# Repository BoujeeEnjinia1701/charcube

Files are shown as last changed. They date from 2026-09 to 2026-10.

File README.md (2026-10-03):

# CharCube

     

**Area:** CleanTech · **TRL:** 3 of 9 (proof of concept on paper; TRL 4 on hold) · **Value-engineering target:** $320 USD (hypothetical control target; estimated cost of the constructable design $546, $226 over, of which the lifting aid is $160; safety kit listed separately) · **Difficulty:** 2 of 5

Batch retort kiln that turns biomass into biochar, with a secondary burner that cleans up the syngas and a jacket that recovers heat for hot water.

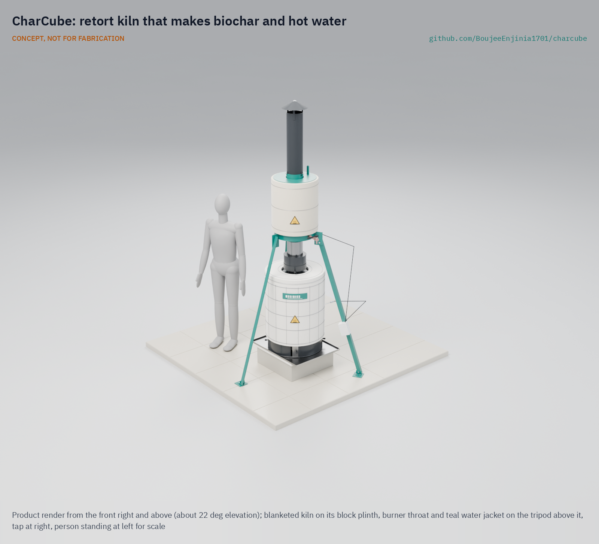
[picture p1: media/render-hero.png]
CharCube: retort kiln that makes biochar and hot water, product render


[Exploded render](media/render-exploded.png) · [Detail render](media/render-detail.png) · [Interactive 3D model](media/viewer.html) · [Concept blueprint (PDF)](media/concept-blueprint.pdf) · [General arrangement CCB-DWG-001 (PDF)](cad/drawings/CCB-DWG-001.pdf) · [Calculations CCB-CAL-001](docs/04-calcs/01-sizing.md) · [Prototype build plan](docs/05-build-plan.md) · [Design decisions](docs/06-design-decisions.md) · [Review note](docs/REVIEW.md)

## Concept rationale

A retort keeps air away from the residue, so it chars instead of burning, and the gas it gives off is burned in the kiln rather than vented. Nesting one steel drum inside another is the simplest way to build that: the gas fire in the gap heats the retort, a burner throat cleans up what is left, and the same flue heats water in an open jacket. Drums, plain pipe, bolts and one welded tank are available almost anywhere crops are grown, so the design can be copied by a village fabricator or a college workshop.

Publishing it as open hardware matters because low-cost kilns rarely come with numbers. CharCube publishes its model, calculations and a temperature logger, so users and researchers can check whether a batch reached the temperatures that make stable char, and improve the design where it falls short.

## Burning platform

In India alone, farms generate about 500 Mt of crop residue a year and burn about 100 Mt of it in the field; that smoke was linked to an estimated 44,000 to 98,000 premature deaths a year between 2003 and 2019 ([Lan et al. 2022, *Nature Communications*](https://www.nature.com/articles/s41467-022-34093-z)). Worldwide, the WHO estimates that outdoor air pollution caused 4.2 million premature deaths in 2019, when 99 % of the world's population lived where its air quality guideline levels were not met ([WHO fact sheet](https://www.who.int/news-room/fact-sheets/detail/ambient-(outdoor)-air-quality-and-health)).

Making char badly is not the answer either. Field measurements found about 54 g of methane per kilogram of charcoal from traditional kilns and about 24 g/kg from improved retorts ([Sparrevik et al. 2015, *Biomass and Bioenergy*](https://www.sciencedirect.com/science/article/abs/pii/S0961953414005170)), and methane at that rate cancels a large part of the carbon the char stores. The gas has to be burned, and the heat is worth using.

## Where it could be used

### By industry

| Industry | Use |
| --- | --- |
| Smallholder farming | Turn stalks, cobs and bundled straw into biochar for the farm's own soil instead of burning them in the field |
| Farmer cooperatives and agricultural NGOs | Shared kilns with logged batches, as a residue service between harvests |
| Agricultural research and extension | A cheap, repeatable kiln with temperature records for feedstock and char quality trials |
| Orchards, vineyards and nurseries | Char prunings on site and use the hot water for cleaning |
| Carbon removal pilots | Small, documented batches as a starting point for biochar measurement and reporting |
| Education and makerspaces | A teaching example of pyrolysis, heat transfer and emissions control |

### By country or region

| Country or region | Why it matters there |
| --- | --- |
| India (Punjab, Haryana, Uttar Pradesh) | About 100 Mt of residue burned a year; these three states account for 67 to 90 % of the linked deaths ([Lan et al. 2022](https://www.nature.com/articles/s41467-022-34093-z)) |
| Southeast Asia | The region produces about 100 to 140 Mt of rice straw a year; with two or three crops a year there is little time for straw to decompose, and open-field burning has risen despite bans ([Van Hung et al. 2020](https://link.springer.com/chapter/10.1007/978-3-030-32373-8_1)) |
| East Africa | Pilot units of a low-cost retort kiln have already been established in East Africa ([Adam 2009, *Renewable Energy*](https://doi.org/10.1016/j.renene.2008.12.009)), so local fabricators and users have seen the principle work |
| Brazil (São Paulo) | [State Law 11,241 of 2002](https://www.al.sp.gov.br/repositorio/legislacao/lei/2002/lei-11241-19.09.2002.html) phases out pre-harvest sugarcane straw burning, by 2021 on land that can be harvested by machine and by 2031 on the rest ([Instituto de Economia Agrícola, 2014](https://iea.agricultura.sp.gov.br/ftpiea/AIA/AIA-31-2014.pdf)), so growers need other uses for residue |
| United States (California) | Rice straw burning in the Sacramento Valley has been capped since 2001 at 25 % of each grower's planted acres ([Health and Safety Code 41865](https://www.countyofglenn.net/sites/default/files/Air_Pollution_Control_District/CARSRA%20%20HSC%2041865.pdf), as published by the Glenn County Air Pollution Control District) |
| Europe | The [European Biochar Certificate](https://www.european-biochar.org/en) sets standards for char quality and production records that a logged kiln can help research groups work toward |

## What sparked the idea

The idea traces back to the Improved Charcoal Production System, or Adam retort, a low-cost retort kiln piloted in India and East Africa and described by J. C. Adam in *Renewable Energy* in 2009 ([Adam 2009](https://doi.org/10.1016/j.renene.2008.12.009)). It burns the harmful volatiles in a hot chamber instead of releasing them and uses the heat of that flare to speed carbonization, reaching 30 to 42 % efficiency against 10 to 22 % for earth mounds and cutting emissions by up to 75 %. It was built for wood charcoal. CharCube asks whether the same principle can be shrunk to two steel drums for crop residue, with the leftover heat sent into water.

## Problem

Crop residue gets burned in the open, releasing carbon and smoke. India alone burns about 100 Mt of residue a year in the field, linked to tens of thousands of premature deaths from smoke. Design with, not for: requirements must come from co-design sessions and field trials with the intended users through a local partner.

## Concept

Batch retort kiln that turns biomass into biochar, with a secondary burner that cleans up the syngas and a jacket that recovers heat for hot water.

A 114 L steel drum packed with 12.0 kg of bundled residue sits inside a 200 L drum. Gas from the heated residue burns in the gap between the drums and again in a burner throat fed by an air shroud, then passes a spiral baffle inside an open-vented, blanketed jacket that holds about 61 L of water. The TRL 3 calculations (CCB-CAL-001 v0.6, central estimates) give about 3.0 kg of biochar per batch in a burn of about 4.5 h with about 3.7 kg of wood, and about 11.5 MJ of hot water. A bolted swinging arm on a post with a hand winch lifts the drained 47 kg heat-recovery unit off the kiln for loading. Value-engineering target: USD 320. Estimated cost of the constructable design: USD 546 (USD 226 over the target), with every part priced; burn time, hot water and start-up wood are at risk. Nothing is measured yet.

Full design precis: [docs/02-concept.md](docs/02-concept.md)

## Key components

- Nested steel drum pair: 200 L outer drum and 114 L inner retort
- Burner throat with secondary air shroud (30 air holes)
- Flue pipe with conical rain cap
- Open-vented water jacket around the flue (replaces the copper coil in the first sketch; decided by Amish, 2026-09-25), with a spiral baffle insert and a mineral wool blanket (decided by Amish, 2026-09-25)
- Ceramic fibre blankets on the outer drum, lid and top band
- Thermocouple logger: retort core, throat exit and a plinth block
- Lifting aid: a swinging arm on a post with a hand winch, for the heat-recovery unit

The priced bill of materials is in [bom/bom.csv](bom/bom.csv). The parametric model is [cad/src/model.py](cad/src/model.py), with STEP and STL exports in `cad/step/` and `cad/stl/`.

## Building the prototype

The [prototype build plan](docs/05-build-plan.md) (CCB-BLD-001) shows how to make and fit every one of the 26 components, in build order, with a making sketch for each made part, close-ups of the joints and a picture for every assembly step. Most of the work is cutting, drilling, rolling and riveting two used drums, plain pipe and sheet; the water jacket is the one welded part. Writing the plan made the design buildable: the jacket now stands on angle legs bolted to fins on its shell, the throat stands in a riveted collar, and the flue rests on the jacket on three clips (CCB-DDR-003, open for review). It is a plan, not yet built; building and testing to it is TRL 4 work, which is on hold.

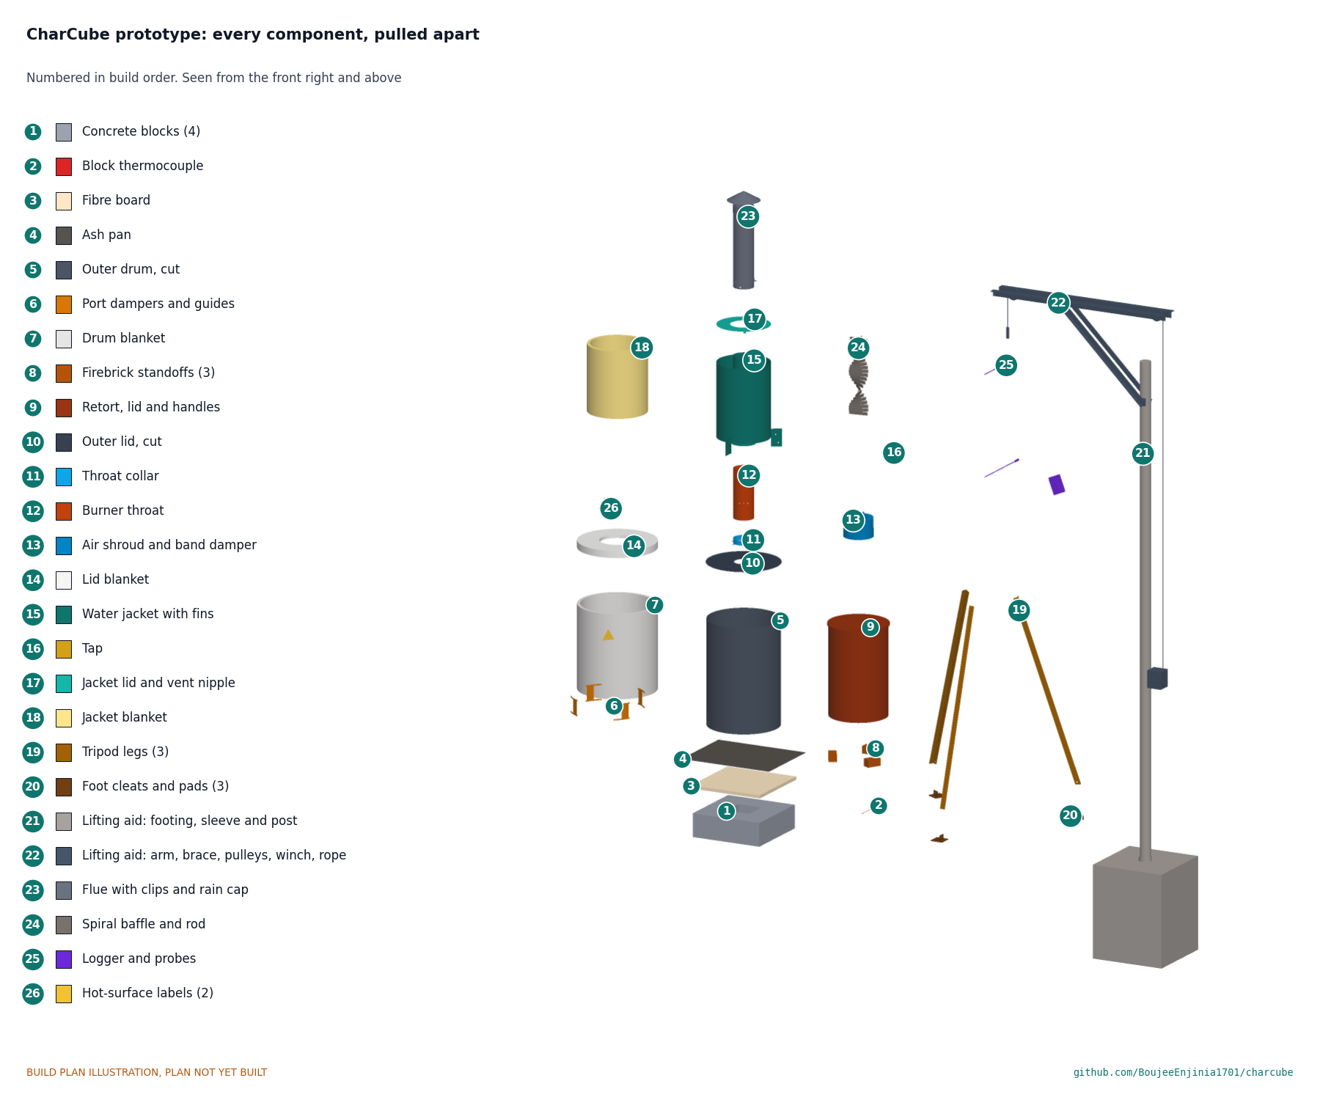
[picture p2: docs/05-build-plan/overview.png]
CharCube prototype: every component, pulled apart and numbered in build order


## Safety

> Involves open flame, hot surfaces (about 125 to 260 °C outside, 400 to 650 °C gas inside), flammable and toxic pyrolysis gas (including carbon monoxide) and water near boiling. Operate outdoors only, at least 5 m from structures and dry vegetation, with the required safety kit (fire suppression, gloves, eye protection) on hand. Never open the kiln while hot, never seal the water jacket, and never use drums that held fuel or chemicals. See the safety section of the [design precis](docs/02-concept.md).

## Repository layout

| Folder | Contents |
| --- | --- |
| `docs/` | Problem, concept, requirements, calculations and design decisions |
| `cad/src/` | build123d Python source, the source of truth for all geometry |
| `cad/step/`, `cad/stl/` | Exported models for FreeCAD, other CAD tools and printing |
| `cad/drawings/` | 2D sketches and dimensioned drawings |
| `bom/` | Bill of materials |
| `electronics/` | KiCad schematics and PCB layouts |
| `firmware/` | Microcontroller code |
| `media/` | Renders, perspectives and photos |
| `build-log/` | Dated prototyping notes |

## Documentation

Controlled documents follow the portfolio [documentation standard](.kit/STANDARDS.md). Each carries a document ID (CCB-PRC-001 for the precis), a version and a revision history. Branded PDFs are built with `python .kit/render.py` and attached to GitHub Releases when a document is tagged, for example `CCB-PRC-001/v1.0`.

## Credits

Designed by Amish Chadha. See [CONTRIBUTORS.md](CONTRIBUTORS.md) for roles. To cite this design, use [CITATION.cff](CITATION.cff) (GitHub shows it as "Cite this repository").

AI assistance (Claude) was used to accelerate concept renders, prototype documentation and first-pass sizing calculations. Design direction and all decisions are Amish Chadha's, recorded in this repository's decision records (`docs/decisions/`).

## Licenses

- **Hardware** (CAD, drawings, BOM, electronics): [CERN-OHL-S v2](LICENSE)
- **Software** (firmware, scripts, notebooks): [MIT](LICENSE-SOFTWARE)

A project of the [Design Molecule](https://designmolecule.com) lab.

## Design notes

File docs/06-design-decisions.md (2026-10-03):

---
doc_id: CCB-DEC-001
title: CharCube design decisions register
project: CharCube
doc_type: Design decisions register
version: "0.5"
status: Draft
date: '2026-10-03'
author: Amish Chadha
license: CERN-OHL-S-2.0
revisions:
  - version: "0.1"
    date: '2026-09-30'
    author: Amish Chadha
    change: Register opened with the open decisions from the review note, the decision records and the build plan work
  - version: "0.2"
    date: '2026-10-01'
    author: Amish Chadha
    change: Budget treated as a value-engineering target
  - version: "0.3"
    date: '2026-10-02'
    author: Amish Chadha
    change: 'Amish approved the recommendations for all seven open decisions (2026-10-02); CCB-DDR-003 accepted; moved to decisions made; value-engineering note on the decided additions'
  - version: "0.4"
    date: '2026-10-02'
    author: Amish Chadha
    change: 'Approved follow-ups carried out: every part priced; value-engineering result restated'
  - version: "0.5"
    date: '2026-10-03'
    author: Amish Chadha
    change: "Amish accepted the cost overrun against the value-engineering target on 2026-10-03; row added to decisions made; value engineering section updated"
---

# CharCube design decisions register

Every design decision still to be made, and every decision made, in one place. Each decision is argued in full in its decision record under `docs/decisions/`; this register is the index Amish works from. The build plan (`docs/05-build-plan.md`, CCB-BLD-001) describes the design as it stands and does not list open decisions.

## Open decisions

None. All open decisions were decided on 2026-10-02.

## To confirm when parts are bought

| # | What to confirm | Why it matters | Source |
| --- | --- | --- | --- |
| 1 | The two drums' actual diameters and heights, and the gap between them (at least 40 mm) | Drum sizes vary by maker; the gas gap, brick positions and probe slot height depend on them | CCB-DDR-003 |
| 2 | The 160 mm pipe's actual outside diameter and the 168 mm sleeve's bore | The collar is rolled to the pipe; the slip joints need about 2 mm clearance | CCB-DDR-003, P2 and P8 |
| 3 | The effect of the 150 mm lid hole on draft (8 % less area than the throat bore), confirmed at the first burn (decided 2026-10-02) | The draft calculation does not model the lid entry; margin 2.4 at peak | CCB-DDR-003, P2; CCB-CAL-001 section 6 |
| 4 | Probe lengths (500 mm and 300 mm) and sheath rating | The core probe must reach the retort axis from outside the blanket | CCB-DDR-003, P12 |
| 5 | Blanket roll widths (681 mm drum strip, 540 mm jacket strip) | Sets how many joins each wrap has | Build plan sections 3.4, 3.14 |
| 6 | Prices of every BOM line once quoted, including the parts added for construction | The estimated cost against the value-engineering target rests on indicative prices | CCB-CAL-001 section 11 |
| 7 | The factor of 3 on gas-side heat transfer and the four velocity heads of pressure loss assumed for the spiral baffle | Heat to water (R6) and draft depend on them; they are assumptions until measured at TRL 4 | CCB-CAL-001 sections 1, 7 |

## Value engineering

Value-engineering target: USD 320. Estimated cost of the constructable design: USD 546 (USD 226 over the target).

Amish accepted this overrun on 2026-10-03: the estimated cost of USD 546 against the USD 320 target (USD 226 over), with the lifting aid (USD 160) counted in the kit cost as it stands. Amish: "Cost over target - i accept all the cost variations and overruns". It stays reported against the target as an accepted overrun, and the savings below remain worth trying.

Every BOM line is priced, with its basis in the line's notes (2026-10-02). The parts added for construction add USD 17 to the earlier USD 319; the additions decided on 2026-10-02 add USD 186: the fibre board USD 28, the block thermocouple USD 10, the hot-surface labels USD 8 and the lifting aid USD 160 (CCB-CAL-001 section 11).

- **Main cost drivers:** the lifting aid (USD 160), the welded water jacket with its spiral baffle insert, the logger, the plinth with its fibre board, the ceramic fibre blankets and the two drums (see `bom/bom.csv`).
- **Savings worth trying:** sharing one lifting aid among several kilns on a site, or hanging the winch from an existing strong beam or tree where there is one (most of USD 160); leaving the fibre board off later builds if a measured burn without it keeps the blocks under about 150 °C (USD 28, as decided); a cheaper logger box; a clay and ash render in place of the side blanket (about USD 25, from the TRL 2 review); and re-pricing the small parts at purchase.

## Decisions made

| Date | Decision | Decided by | Record |
| --- | --- | --- | --- |
| 2026-09-25 | TRL 2 review items 1 to 8 and 10: open-vented annular water jacket; $300 kiln budget with the safety kit separate; nested-drum retort; bundled straw and stalks first; burner throat with preheated air; logger as standard; ceramic fibre blanket; tripod-carried jacket; keep the name | Amish: "proceed with all of your recommendations across all batches. Make sure we don't proceed to TRL 4 on any of them." | CCB-DDR-001 |
| 2026-09-25 | Items 11 to 16: air shroud in place of the 25 mm ring; spiral baffle insert and jacket blanket; lid and top band blanket; R5 relaxed to 5 h; R9 restated to 700 °C; safety kit stated in R10 and the BOM notes | Amish: "i accept all your recommendations, go with them across all repos." | CCB-DDR-002 |
| 2026-09-26 | Item 17: budget top-up from $300 to $320 for kiln parts | Amish: "I am ok with the budget top ups." | CCB-DDR-002, Table 1a |
| 2026-09-25 | TRL 4 on hold | Amish | `project.yaml`; CCB-DDR-001 |
| 2026-09-30 | Make the design physically buildable while drawing the build plan; outstanding decisions kept in this register, not in the build plan | Amish: "If you are realising that the design cannot be built as per concept - fix the design assumptions to match and be physically feasible as you draw the illustrations." | CCB-DDR-003 (accepted on 2026-10-02, below) |
| 2026-10-02 | Design for construction accepted: the twelve changes of Table 1 and their knock-on changes, as made; the first burn confirms that the 150 mm lid hole (8 % less area than the throat bore) does not limit draft | Amish: "i approve your recommendations for all 555 open decisions." | CCB-DDR-003, Table 1 |
| 2026-10-02 | Plinth: a 25 mm ceramic fibre board between the pan and the blocks from the first burn, with a thermocouple on a block; the board is dropped on later builds only if a measured burn without it keeps the blocks under about 150 °C | Amish: "i approve your recommendations for all 555 open decisions." | CCB-DDR-003, A2 |
| 2026-10-02 | Jacket sleeve: the welder flares the bottom 20 mm of the sleeve to about 190 mm so it guides itself onto the throat | Amish: "i approve your recommendations for all 555 open decisions." | CCB-DDR-003, A3 |
| 2026-10-02 | Heat-recovery unit: a lifting aid, a swinging arm on a post or a hand winch, is designed for the first build; users are asked through the partner how it should work, not whether it is needed | Amish: "i approve your recommendations for all 555 open decisions." | CCB-PRC-001, open questions |
| 2026-10-02 | First region, residue and partner: kept open under the portfolio rule, chosen by this rule: a region where rice or wheat straw is still burned in the open, with a partner that already runs residue or biochar trials. First candidate to approach: an agricultural university's extension service, for example Punjab Agricultural University in India | Amish: "i approve your recommendations for all 555 open decisions." | CCB-DDR-001 item 9; CCB-DDR-002 Table 2 |
| 2026-10-02 | Rain cap: the conical cap is adopted in the model and drawings, on the three flat-bar legs and 60 mm gap set by the design for construction | Amish: "i approve your recommendations for all 555 open decisions." | `docs/REVIEW.md`, 2026-09-26, appearance item 1 |
| 2026-10-02 | Hot-surface labels: durable ISO 7010 W017 hot-surface warning labels for the drum blanket and the jacket are added to BOM line 14 | Amish: "i approve your recommendations for all 555 open decisions." | `docs/REVIEW.md`, 2026-09-26, appearance item 5 |
| 2026-10-03 | Cost overrun accepted: the estimated cost of USD 546 against the USD 320 target (USD 226 over), with the lifting aid (USD 160) counted in the kit cost as it stands | Amish: "Cost over target - i accept all the cost variations and overruns" | [REVIEW.md](REVIEW.md), session 2026-10-03 |

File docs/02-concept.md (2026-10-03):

---
doc_id: CCB-PRC-001
title: CharCube design precis
project: CharCube
doc_type: Design precis
version: "0.9"
status: Draft
date: '2026-10-02'
author: Amish Chadha
license: CERN-OHL-S-2.0
revisions:
- version: "0.1"
  date: '2026-09-24'
  author: Amish Chadha
  change: Initial scaffold
- version: "0.2"
  date: '2026-09-25'
  author: Amish Chadha
  change: Populate to TRL 2 (architecture, first-order numbers, design choices, safety, media)
- version: "0.3"
  date: '2026-09-25'
  author: Amish Chadha
  change: TRL 3 update; decisions of 2026-09-25 recorded (CCB-DDR-001), numbers replaced by CCB-CAL-001 results, air shroud replaces the 25 mm ring, parametric model and CCB-DWG-001
- version: "0.4"
  date: '2026-09-25'
  author: Amish Chadha
  change: Recommendations accepted by Amish (DDR-002); spiral baffle insert, jacket blanket and lid blanket added, 30 throat air holes, numbers from CCB-CAL-001 v0.2, CCB-DWG-001 Rev P2
- version: "0.5"
  date: '2026-09-26'
  author: Amish Chadha
  change: Budget top-up approved by Amish ($320, CCB-DDR-002 item 17); R10 met
- version: "0.6"
  date: '2026-09-30'
  author: Amish Chadha
  change: Design made constructable (CCB-DDR-003, Draft); components table, masses and probe routes updated; build plan CCB-BLD-001
- version: "0.7"
  date: '2026-10-01'
  author: Amish Chadha
  change: Budget treated as a value-engineering target
- version: "0.8"
  date: '2026-10-02'
  author: Amish Chadha
  change: 'Decisions of 2026-10-02 carried in: lifting aid, fibre board under the drum floor, hot-surface labels, conical rain cap, partner selection rule and first candidate'
- version: "0.9"
  date: '2026-10-02'
  author: Amish Chadha
  change: 'Approved follow-ups carried out: lifting aid designed and priced (item 18), fibre board and block thermocouple, sleeve flare, labels; every part priced ($546, R10 not met); outlet 2.72 m'
---

# CharCube design precis

CharCube is a batch retort kiln made from a 114 L (30 US gal) steel drum sealed inside a 200 L (55 US gal) drum. Crop residue packed into the inner drum (the retort) is heated without air; the gas it gives off escapes through holes in the retort base and burns in the gap between the drums, which keeps the process going. The flame and any unburned gas then pass through a burner throat fed with secondary air, and the hot flue gas rises past a spiral baffle through an open-vented, blanketed water jacket of about 61 L before leaving a flue 2.70 m above the ground. The TRL 3 calculations (CCB-CAL-001 v0.4) give, for the central case: 12.0 kg of air-dry residue per batch makes about 3.0 kg of biochar in a burn of about 4.5 h using about 3.7 kg of wood, and heats the water by about 45 K (11.5 MJ). Against the $320 value-engineering target (a hypothetical control target), the estimated cost of the kiln parts is $319, $1 under the target, so cost (R10) is within the target; burn time, hot water and start-up wood (R5, R6, R8) are at risk.

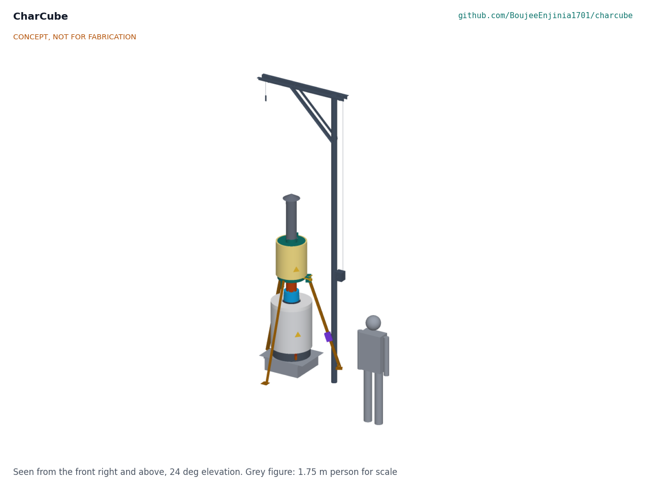
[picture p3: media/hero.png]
Hero render


*Figure 1. CharCube on its block plinth with the jacket tripod, beside a 1.75 m person for scale. TRL 3 parametric model (`cad/src/model.py`).*

## How it works

1. **Load.** The retort is packed to 600 mm with 12.0 kg of air-dry residue (bundled straw, stalks, cobs or prunings), its lid is clamped on, and it stands upright on three firebrick standoffs inside the outer drum. The outer lid, carrying the burner throat and its blanket, goes on top, and the tripod carrying the drained jacket and flue is set over it so the jacket sleeve slips over the top of the throat.
2. **Light.** Dry wood is lit in the 53 mm annulus around the retort and in the space beneath it; about 1.7 kg brings the kiln up to temperature, and more is fed to keep the annulus hot (about 3.7 kg in all, central estimate). Primary air enters through four ports near the base of the outer drum.
3. **Pyrolysis.** After about 30 to 45 min the retort contents pass about 300 °C and start to release gas and tar vapor. The gas leaves through holes in the retort base, meets the fire and burns. The retort gas then supplies much of the heat, but CCB-CAL-001 shows that wood must still be fed to hold the annulus near 650 °C for the whole burn. The target is a retort core of 450 to 600 °C for at least 30 min. Heat conducts slowly into the packed charge, so the core reaches 450 °C about 4.0 h after lighting (2.9 to 6.5 h).
4. **Clean-up burn.** Everything leaving the outer drum passes the burner throat, a 160 mm steel pipe 400 mm long. A 230 mm sleeve (the air shroud) around its base admits secondary air, preheated by the throat wall, through 30 holes of 12 mm, so gas that escaped the annulus fire burns there instead of leaving as smoke and methane.
5. **Heat recovery.** The hot gas (about 400 to 465 °C at the throat exit, after mixing with the secondary air) rises through a 168 mm sleeve that forms the centre of an annular water jacket. The gas flow is laminar or transitional, so a twisted steel strip (the spiral baffle insert) swirls it against the sleeve wall, and a mineral wool blanket on the jacket shell keeps the heat in the water. The jacket is open at the top, so it cannot build pressure. Hot water is drawn from a tap at its base.
6. **Finish and cool.** When the flame at the throat dies back (about 4.5 h after lighting; 3.4 to 7.0 h), the primary ports and secondary damper are closed and the kiln is left sealed overnight. The char cools without air, so it does not burn away.
7. **Unload and log.** Next morning the tripod unit and lid are lifted off, the core probe is pulled out, the retort (about 15.5 kg with its char) is lifted out by its two U-bolt handles, and the char is tipped out, quenched or wetted, weighed and crushed. A two-channel thermocouple logger records the retort core and the throat exit every 10 s, giving a record of peak temperature and time at temperature for each batch.

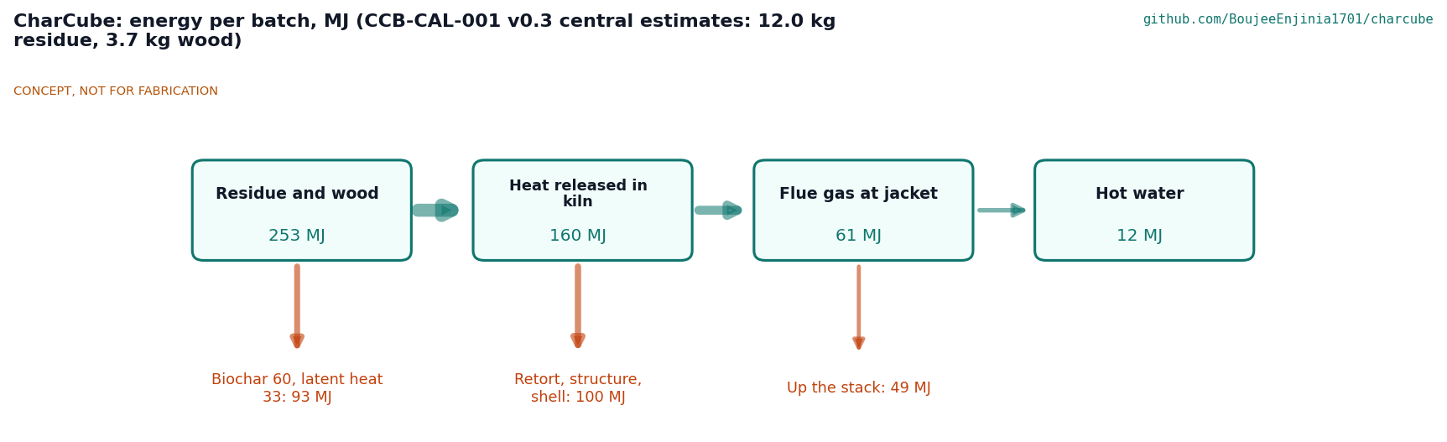
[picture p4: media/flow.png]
Energy flow


*Figure 2. Energy per batch, central estimates from CCB-CAL-001 v0.2: 12.0 kg of residue at 16.0 MJ/kg (air-dry, higher heating value) plus 3.7 kg of wood at 16.2 MJ/kg (lower heating value); 2.96 kg of char at 20.2 MJ/kg; with the baffle and jacket blanket the jacket takes about 19 % of the flue gas heat.*

## Main components

Table 1. Main components. Numbers match `bom/bom.csv`, Figure 4 and CCB-DWG-001. Dimensions are the parameters of `cad/src/model.py`.

| # | Component | Choice | Notes |
| --- | --- | --- | --- |
| 1 | Outer drum (firebox shell) | 200 L open-head steel drum, 572 mm diameter x 851 mm, four 40 x 110 mm primary air ports with sliding dampers in riveted guides | Used drum; must have held a non-flammable, non-toxic product and be burned clean of paint before use |
| 2 | Outer lid with flue collar | The drum's own lid with a 150 mm hole and a 160 mm bore collar, 40 mm high, riveted on by six tabs; the throat stands on the lid inside it | Sealed with ceramic gasket rope and the drum's locking ring |
| 3 | Inner retort | 114 L open-head steel drum, 463 mm diameter x 737 mm, bolt-ring lid, eight 20 mm gas holes on a 300 mm circle in the base, a slot for the core probe, two U-bolt handles on the lid | Holds the feedstock; replaced when it scales through (estimate 50 to 100 batches) |
| 4 | Firebrick standoffs | Three half firebricks, 60 mm high, laid round the retort's edge clear of the gas holes | Leave room for fire under the retort |
| 5 | Secondary air shroud | 230 mm sleeve, 150 mm high, around the throat base; closed top riveted to the throat, open bottom with a sliding band damper | Replaces the 25 mm pipe ring of TRL 2, which could not pass the air (CCB-CAL-001 section 6); decided by Amish, 2026-09-25 (CCB-DDR-002 item 11) |
| 6 | Burner throat (afterburner) | 160 x 2 mm plain steel pipe, 400 mm long, two staggered rings of 15 air holes of 12 mm (30 in all) inside the shroud | The jacket sleeve slips over its top end; 30 holes offset the baffle pressure drop |
| 7 | Flue pipe with rain cap | 160 x 2 mm plain (not galvanized) steel, 650 mm, its foot 50 mm inside the jacket sleeve, resting on the sleeve rim on three riveted clips; conical rain cap (decided by Amish, 2026-10-02) on three riveted legs, at least 60 mm from the flue's top edge | Outlet 2.72 m above the ground |
| 8 | Water jacket | Annular steel tank, 420 mm outside diameter x 600 mm, 2 mm walls, around an integral 168 mm flue sleeve whose foot is flared to about 190 mm; about 61 L at 540 mm depth; open top with a loose lid and 24 mm vent | The one welded, water-tight part; local fabricator |
| 9 | Draw-off tap | 1/2 in brass ball valve with a short nipple | Drains the jacket before moving it |
| 10 | Jacket support tripod | Three 40 x 40 x 4 mm angle legs, each bolted to a fin welded on the jacket and pinned to a bolted foot cleat and pad; feet on a 1.44 m circle | Carries the jacket and flue so the drum lid carries no water load |
| 11 | Insulation blanket | 25 mm ceramic fibre blanket held by wire mesh, air ports left clear | Halves the shell loss (CCB-CAL-001 section 4) |
| 12 | Plinth | Four concrete blocks laid as a pinwheel, a 25 mm ceramic fibre board on them and a steel ash pan on the board | Lifts the air ports clear of the ground and keeps embers off it; the board shields the blocks from the heat (decided by Amish, 2026-10-02) |
| 13 | Thermocouple logger | Two type K class 1 probes (retort core, in through the drum side; throat exit, below the jacket) and a bare-wire type K on a plinth block, three MAX31855 amplifiers, a small microcontroller and microSD card, USB power bank | Strapped beside a tripod leg, away from the heat |
| 15 | Spiral baffle insert | 1.5 mm steel strip 150 mm wide, twisted half a turn per 300 mm, in the jacket sleeve, hung on a rod through the foot of the flue | Triples gas-side convection (assumption); lifts out with the flue for tar and soot cleaning; decided by Amish, 2026-09-25 (CCB-DDR-002 item 12) |
| 16 | Jacket shell blanket | 25 mm mineral wool on the jacket side, held by wire; tap, vent and lid clear | Cuts the jacket shell loss; decided by Amish, 2026-09-25 (item 12) |
| 17 | Lid and top band blanket | 25 mm ceramic fibre disc on the lid, clear of the shroud intake, with a skirt over the top band and locking ring | Saves 1.22 kW of shell loss; lifted off with the lid; decided by Amish, 2026-09-25 (item 13) |
| 18 | Lifting aid | A post 4.0 m high turning in a ground sleeve 1.2 m behind the kiln, a bolted arm and brace of steel angle, two pulleys, a hand brake winch and a hook; a 16 mm bar through the jacket sleeve's top socket | Raises the drained heat-recovery unit 1.55 m and swings it clear, so nobody carries it; decided by Amish, 2026-10-02 |

Of item 14 (fasteners, gasket rope, high-temperature sealant, hot-surface labels) only the two hot-surface labels are modelled.

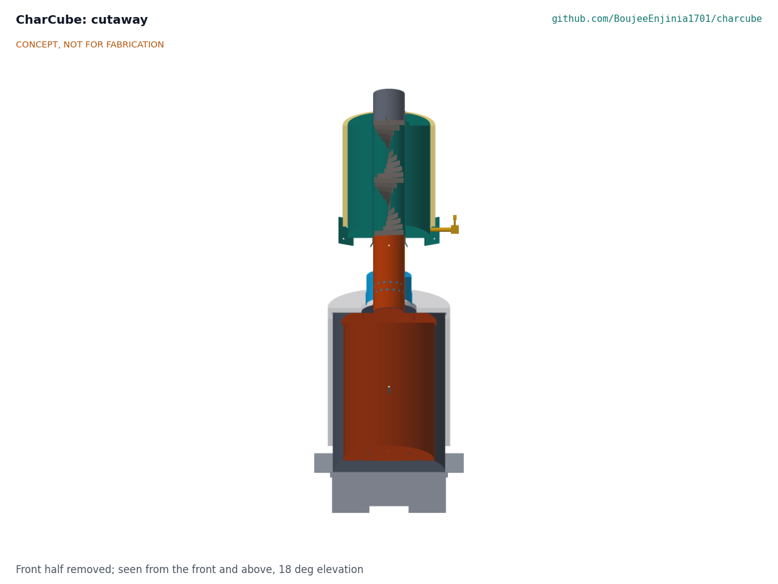
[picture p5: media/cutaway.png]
Cutaway


*Figure 3. Section looking from the front: retort (3) inside the outer drum (1) with the gas annulus between them, insulation (11, 17) outside and on the lid, lid (2), air shroud (5) and burner throat (6) above, then the blanketed (16) water jacket (8) around its flue sleeve with the spiral baffle (15), and the tap (9). Tripod and logger omitted.*

## Numbers from the TRL 3 calculations

All values are central estimates from CCB-CAL-001 v0.2 (`docs/04-calcs/sizing.py`), with the favourable to unfavourable range where it matters. Assumptions are listed there: air-dry feed at 12 % moisture packed to 120 kg/m³, a dry feed analysis typical of maize and cotton stalks, 28 % char yield, and the annulus held at 650 °C until the core reaches 450 °C. Nothing is measured.

Table 2. Batch, energy, carbon and cost.

| Quantity | Value | Requirement |
| --- | --- | --- |
| Retort fill | 100 L at 600 mm depth (123 L geometric) | |
| Feed per batch | 12.0 kg air-dry (10.58 kg dry); loose chopped straw would give 4.0 kg and is outside the decided feedstock | R1 met |
| Biochar | 2.96 kg (2.12 to 3.70 kg) at 28 % (20 to 35 %); about 29 % ash, 20.2 MJ/kg | R2 at risk |
| Core at 450 °C | 4.0 h after lighting (2.9 to 6.5 h) | R3 at risk |
| Burn, light to end of flaming | 4.5 h (3.4 to 7.0 h) | R5 (5 h, relaxed) at risk |
| Sealed cooling; unload | About 3.6 h; unload about 8 h after lighting, though overnight is safer | R5 16 h limit met |
| Start-up and support wood | 3.7 kg (1.7 to 9.8 kg); light-up alone 1.7 kg | R8 at risk |
| Heat released in the kiln | 160 MJ (125 to 247 MJ) | |
| Shell loss while burning | 4.47 kW: blanketed side 125 °C, blanketed lid 120 °C, bare lid under the shroud 257 °C, throat 223 °C | |
| Stack draft | 16.7 Pa over 2.43 m; peak losses about 7 Pa including the gas holes and baffle, margin 2.4 | R4 air paths sized |
| Secondary air holes | 33.9 cm² (30 x 12 mm) provided against 28.5 cm² needed at peak | R4 |
| Heat to water | 11.5 MJ (9.0 to 19.1 MJ) with the baffle and jacket blanket; 61 L raised about 45 K; no boiling in any case, but the long burn comes within 1.5 MJ of it | R6 at risk |
| Carbon stored for 100 years | 1.30 kg C, 4.8 kg CO₂ per batch (2.96 kg x 0.55 x 0.80) | |
| Methane penalty | 2.0 kg CO₂e per batch at the retort field average (24 g CH₄ per kg char, GWP100 28) | R4 not verifiable |
| Net removal | 2.8 kg CO₂e per batch (2.0 to 3.5); 0.70 t CO₂e and about 740 kg of char a year at 250 batches; about 3.0 t of residue kept out of open burning | |
| Mass | About 97 kg without plinth and water; lift unit (tripod, drained jacket with baffle and blanket, flue) 47.2 kg, raised by the lifting aid; retort with char 15.5 kg; full jacket 85 kg | R11 met |
| Height | Flue outlet 2.72 m; 2.84 m to the top of the rain cap; footprint about 1.44 m across the tripod feet; lifting aid post 4.0 m | R12 met |
| Parts cost | Value-engineering target: USD 320. Estimated cost of the constructable design: USD 546 (USD 226 over the target); the lifting aid is $160 of it; safety kit (about $40) listed separately | R10 not met |

The main changes from TRL 2: the char carries its ash, so its mass and heating value are lower; the burn is set by conduction into the charge and is longer; a longer burn needs more wood; and the plain jacket sleeve transfers about a third of the heat assumed at TRL 2. The changes accepted on 2026-09-25 (CCB-DDR-002) recover most of that: the baffle and jacket blanket take hot water from 6.4 to 11.5 MJ, and the lid blanket takes wood from 5.8 to 3.7 kg, at a cost of $21 and a lower draft margin.

## Key design choices

Items 1 to 8 and 10 of the TRL 2 review (CCB-DDR-001) and items 11 to 16 of the TRL 3 review (CCB-DDR-002) were decided by Amish on 2026-09-25: go with the recommendation.

- **Nested-drum retort rather than a flame-curtain kiln.** Decided by Amish, 2026-09-25. A Kon-Tiki cone costs less and needs no start-up wood, but it is open, its heat cannot be recovered and its yield on straw is lower.
- **Annular water jacket on the flue rather than a copper coil.** Decided by Amish, 2026-09-25. It needs no pump or raised tank and cannot build pressure. CCB-CAL-001 showed it recovers only about 6.4 MJ per batch with a plain sleeve, so a spiral baffle insert and a jacket blanket were added (decided by Amish, 2026-09-25, CCB-DDR-002 item 12), giving about 11.5 MJ.
- **Burner throat with preheated secondary air.** Decided by Amish, 2026-09-25. The TRL 3 sizing replaced the 25 mm pipe ring with an air shroud (decided by Amish, 2026-09-25, CCB-DDR-002 item 11).
- **Jacket carried on a tripod, not on the drum lid.** Decided by Amish, 2026-09-25. The drained lift unit weighs 47.2 kg. The legs bolt to three fins welded on the jacket (CCB-DDR-003). The lifting aid (item 18, decided by Amish, 2026-10-02) is a swinging arm on a post with a hand winch; users are asked through the partner how it should work.
- **Target feedstock.** Decided by Amish, 2026-09-25: bundled straw and mixed stalks and cobs first; a straw press is a separate project.
- **Temperature logging as standard.** Decided by Amish, 2026-09-25. Class 1 probes meet the restated R9, ±5 °C to 700 °C and indicative above (CCB-DDR-002 item 15).
- **Insulation blanket.** Decided by Amish, 2026-09-25: ceramic fibre for the prototype, now also on the lid and top band (CCB-DDR-002 item 13), which saves 1.22 kW.
- **Burn time target.** Decided by Amish, 2026-09-25: R5 relaxed to 5 h (CCB-DDR-002 item 14).
- **Value-engineering target.** Value-engineering target: $320 (a hypothetical control target, not a limit) for the kiln parts; the safety kit is required and listed separately (decided by Amish, 2026-09-25). Value-engineering target: USD 320. Estimated cost of the constructable design: USD 546 (USD 226 over the target), with every part priced (CCB-CAL-001 section 11).
- **Name.** Decided by Amish, 2026-09-25: keep CharCube.

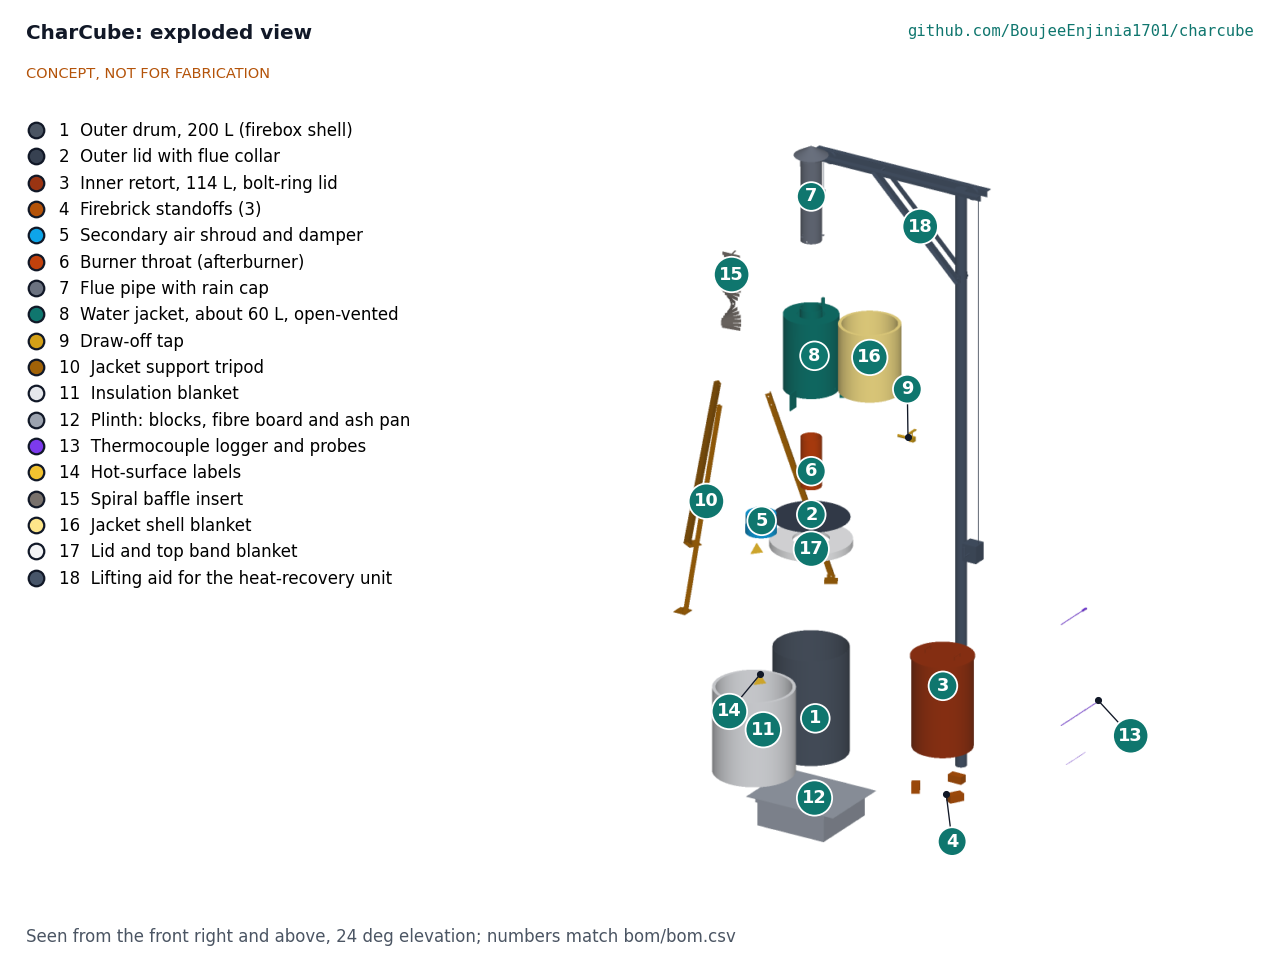
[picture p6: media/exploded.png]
Exploded view


*Figure 4. Exploded view with BOM numbers.*

## Safety

> **Safety:** CharCube is a fire. CCB-CAL-001 estimates about 125 °C on the blanket and 170 to 260 °C on average over the bare port band, lid and throat, with hotter spots at gaps, the collar and the air ports; the gas inside is at 400 to 650 °C, and the char stays hot enough to reignite for many hours. Run it outdoors only, on bare soil or paving, at least 5 m from buildings, fences, dry vegetation and residue piles, never under trees or roofs, and never during a local burning ban or high wind. Keep a fire extinguisher or at least 50 L of water and a shovel at hand, keep children and animals outside a marked 3 m circle, and wear heat-resistant gloves, eye protection and closed shoes. This safety kit is required for every batch; it is listed separately from the kiln parts cost (CCB-REQ-001 R10).

> **Safety:** Pyrolysis gas is flammable and toxic (carbon monoxide, hydrogen, methane and tar vapor). Never open the retort or the outer lid while the kiln is hot: air entering a hot retort can ignite the gas suddenly and throw flame. Do not stand over the flue or downwind of the throat, never run the kiln in or near an enclosed space, and stop a batch that smokes heavily rather than leaving it.

> **Safety:** With the baffle insert and jacket blanket, a long batch brings the water close to boiling (CCB-CAL-001 v0.2 estimates 19.1 MJ against 20.6 MJ to boil 61 L from 20 °C), and a warm start or a low level would boil it. It must stay open to the air: never plug the vent or fit a sealed lid, and never connect it to household plumbing or a closed tank. Keep it at least three-quarters full while the kiln runs, never add cold water to a jacket that has boiled dry, and draw hot water slowly through the tap. Scalds from 80 °C water happen in under a second.

- **Used drums.** Use only open-head drums that held non-flammable, non-toxic products. Never cut, drill or grind a drum that held fuel, solvent or pesticide, and burn paint and liners off outdoors, upwind, before first use. Do not use galvanized pipe or drums: heated zinc gives off toxic fumes.
- **Char handling.** Tip char out only after overnight cooling, onto bare ground, and quench or wet it before bagging. Dry char dust is a fire and inhalation hazard; wet it and wear a dust mask when crushing.
- **Lifting.** Drain the jacket before moving it. The tripod, jacket and flue unit weighs about 47 kg empty and must be raised about 1.55 m to clear the kiln, so it is moved only with the lifting aid's winch, with the flue lifted out first and nobody under the load; a full jacket weighs about 85 kg and must never be moved; move it only when the flue is cool enough to handle with gloves.
- **Hot plinth.** A 25 mm ceramic fibre board lies between the ash pan and the concrete blocks from the first burn, with a thermocouple on a block, because concrete can crack or spall when heated (decided by Amish, 2026-10-02).
- **Warning labels.** Durable hot-surface warning labels (ISO 7010 W017) go on the drum blanket and the jacket (decided by Amish, 2026-10-02).
- **Sharp edges.** Cut drum edges and air ports must be deburred or folded.
- **Baffle and blankets.** Lift the baffle insert out with the flue only when cool, and scrape tar outdoors with gloves. Wear a dust mask when cutting ceramic fibre or mineral wool, and keep the lid blanket clear of the shroud intake so the secondary air is not blocked.
- **Temperature logger.** Keep the logger and power bank on the tripod leg away from the heat; thermocouple leads must be rated for the temperature where they run.

## Open questions

The TRL 3 open questions on gas holes, secondary air, draft, jacket heat transfer and surface temperatures are answered in CCB-CAL-001. What remains:

- How much does the spiral insert really raise heat transfer, and how fast does it foul? The factor of 3 is an assumption.
- How should the lifting aid for the 47 kg heat-recovery unit work (a swinging arm on a post or a hand winch)? Ask users through the partner (decided by Amish, 2026-10-02, that one is needed).
- How fast does tar foul the jacket sleeve, and how is it cleaned?
- Establish the batch record needed for a biochar certificate, even if certification stays out of scope.
- First region, residue and partner: kept open under the portfolio rule and chosen by this rule (decided by Amish, 2026-10-02): a region where rice or wheat straw is still burned in the open, with a partner that already runs residue or biochar trials. The first candidate to approach is an agricultural university's extension service, for example Punjab Agricultural University in India; nothing is agreed.
- Validate feedstock, packing, batch size, water use and price with users through a local partner.

TRL 4 (building and logging batches) is on hold by Amish's instruction.

Concept media: [blueprint sheet](../media/concept-blueprint.pdf), [interactive 3D model](../media/viewer.html). General arrangement: [CCB-DWG-001](../cad/drawings/CCB-DWG-001.pdf). Prototype build plan: [CCB-BLD-001](05-build-plan.md). Calculations: [CCB-CAL-001](04-calcs/01-sizing.md).

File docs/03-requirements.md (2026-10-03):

---
doc_id: CCB-REQ-001
title: CharCube requirements
project: CharCube
doc_type: Requirements
version: "0.9"
status: Draft
date: '2026-10-02'
author: Amish Chadha
license: CERN-OHL-S-2.0
revisions:
- version: "0.1"
  date: '2026-09-24'
  author: Amish Chadha
  change: Initial scaffold
- version: "0.2"
  date: '2026-09-25'
  author: Amish Chadha
  change: First measurable requirements for TRL 2, with status against the concept estimates
- version: "0.3"
  date: '2026-09-25'
  author: Amish Chadha
  change: Apply Amish's 2026-09-25 decisions (CCB-DDR-001); R1 limited to the decided feedstock, R10 redefined to exclude the required safety kit, R9 probe class stated; status from CCB-CAL-001
- version: "0.4"
  date: '2026-09-25'
  author: Amish Chadha
  change: Recommendations accepted by Amish (DDR-002); R5 relaxed to 5 h, R9 restated to 700 °C, R10 notes the safety kit; status from CCB-CAL-001 v0.2
- version: "0.5"
  date: '2026-09-26'
  author: Amish Chadha
  change: Budget top-up approved by Amish
- version: "0.6"
  date: '2026-09-30'
  author: Amish Chadha
  change: R11 figures from CCB-CAL-001 v0.4 (constructable design, CCB-DDR-003); no status changed
- version: "0.7"
  date: '2026-10-01'
  author: Amish Chadha
  change: Budget treated as a value-engineering target
- version: "0.8"
  date: '2026-10-02'
  author: Amish Chadha
  change: 'Decision of 2026-10-02: lifting aid for the heat-recovery unit noted under R11'
- version: "0.9"
  date: '2026-10-02'
  author: Amish Chadha
  change: 'Approved 2026-10-02 follow-ups carried out: every part priced, R10 now not met ($546 against $320); R11 re-judged with the lifting aid (met); outlet 2.72 m; block thermocouple noted under R9'
---

# CharCube requirements

These are first-pass requirements for the concept. Targets are proposals for review, not user-validated needs, and will be revised after co-design sessions. R1 and R10 were redefined by Amish's decisions of 2026-09-25 (CCB-DDR-001 items 2 and 4); R5 was relaxed and R9 restated by his acceptance of the TRL 3 recommendations on the same day (CCB-DDR-002 items 14 and 15). R10's value-engineering target is $320 (a hypothetical control target, not a limit; see the design decisions register). The status column gives the TRL 3 result from CCB-CAL-001 v0.4 (central estimate, with the range where it matters): met, not met, at risk, or not verifiable at TRL 3 (cost is reported against the value-engineering target).

| ID | Requirement | Target | Verification (TRL 3 or later) | Status at TRL 3 (CCB-CAL-001) |
| --- | --- | --- | --- | --- |
| R1 | Process a useful batch | 10 kg or more of air-dry residue (15 % moisture or less) per batch, **for the decided feedstock: bundled straw and mixed stalks and cobs, packed to about 120 kg/m³**. Loose straw is out of scope without a press (a separate project) | Retort volume and packed bulk density | Met: 12.0 kg (10.58 kg dry) |
| R2 | Make biochar efficiently | Biochar 25 % or more of dry feed mass | Mass balance; later weighed batches | At risk: 28 % (20 to 35 %), 2.96 kg |
| R3 | Make stable char | Retort core at 450 °C or more for 30 min or more per batch, logged; target molar H/Corg below 0.7, the [European Biochar Certificate](https://www.european-biochar.org/en) limit | Heat conduction and balance; later logged batches and lab analysis | At risk: core at 450 °C about 4.0 h after lighting (2.9 to 6.5 h), only if the annulus is kept hot |
| R4 | Burn the gas, not vent it | All retort gas passes the annulus fire and the burner throat; visible smoke only during the first 15 min after lighting and the last 10 min of a batch; methane below 24 g per kg of char (the retort field average in [Sparrevik et al. 2015](https://www.sciencedirect.com/science/article/abs/pii/S0961953414005170)) | Design review and air sizing; later emission measurement with a partner lab | Not verifiable at TRL 3: route closed, draft margin 2.4 with the baffle insert, throat holes (30) sized with 19 % spare area |
| R5 | Fit a daily routine | Light to end of flaming in **5 h** or less (relaxed from 4 h, CCB-DDR-002 item 14); char ready to unload within 16 h of lighting | Heat conduction and cooling; later logged batches | At risk: burn about 4.5 h (3.4 to 7.0 h); unload after about 8 h is met |
| R6 | Recover heat as hot water | 10 MJ or more into water per batch (60 L raised by 40 K) | Heat transfer; later measured water temperature | At risk: 11.5 MJ (9.0 to 19.1 MJ) with the spiral baffle insert and jacket blanket, about 45 K rise |
| R7 | Keep the water circuit safe | Jacket open to the air at all times; no valve or cap that can seal it; water drawn from a tap at the base; jacket kept away from the lid by a separate support | Design review and safety checklist | Met by design |
| R8 | Use little start-up fuel | 5 kg or less of dry wood per batch | Energy balance; later weighed batches | At risk: 3.7 kg with the lid blanket (1.7 to 9.8 kg); light-up alone 1.7 kg |
| R9 | Record each batch | Two type K channels (retort core, throat exit), class 1 probes, **±5 °C or better from 0 to 700 °C and indicative from 700 to 1,000 °C** (restated, CCB-DDR-002 item 15), logged every 10 s to removable storage, 24 h on a USB power bank | Component data; design review | Met: ±3.4 °C to 700 °C with class 1 probes; energy 6 of 31 Wh. A third, bare-wire type K channel on a plinth block (decided 2026-10-02) is a first-burn check, not part of R9 |
| R10 | Keep the estimated cost within the value-engineering target | Kiln parts **$320** or less (a hypothetical control target, not a limit). **The safety kit (extinguisher or water and shovel, gloves, eye protection, dust mask, about $40) is required and listed separately, outside the kiln parts target**; this requirement and `bom/bom-notes.md` are where the safety kit is stated (CCB-DDR-002 item 16) | Priced BOM | Not met: Value-engineering target: USD 320. Estimated cost of the constructable design: USD 546 (USD 226 over the target) |
| R11 | Be built and handled by a small crew | Built with hand tools, drill and angle grinder, with at most one welded part (the water jacket); no single lift above 25 kg per person | Masses from the model; design review | Met: the 47.2 kg unit is raised by the bolted lifting aid's winch; heaviest hand lift the retort with char, 15.5 kg |
| R12 | Operate safely outdoors | Flue outlet 2.5 m or more above the ground; 5 m clear radius from structures and dry vegetation; no galvanized parts in the hot path | Model and BOM; safety checklist | Met: outlet 2.72 m; no galvanized lines |

## Requirements at risk or outside their targets

- **R10 not met.** Value-engineering target: USD 320. Estimated cost of the constructable design: USD 546 (USD 226 over the target). The parts added for construction add $17 and the additions decided on 2026-10-02 add $186, of which the lifting aid is $160 (CCB-CAL-001 section 11). Without the lifting aid the estimate would be $386. The target is a hypothetical control target, not a limit; it keeps the design under a value-engineering lens.
- **R5 at risk.** The central burn (about 4.5 h) meets the relaxed 5 h target, but a poorly conducting charge could take about 7 h.
- **R6 at risk.** The baffle insert and jacket blanket lift the central estimate to 11.5 MJ, but a short burn gives about 9.0 MJ, and the convection gain of the insert is an assumption until measured.
- **R8 at risk.** The lid blanket brings the central wood demand to 3.7 kg, but a long burn could need about 9.8 kg.
- **R2 and R3 at risk.** Yield and core temperature depend on feedstock and operation.
- **R4** cannot be shown without emission measurement.
- **R11** is met with the lifting aid decided by Amish on 2026-10-02: a bolted swinging arm on a post with a hand winch raises the drained 47 kg unit 1.55 m and swings it clear, so nobody carries it. The jacket must still be drained first.

## Assumptions

- Feedstock (decided): bundled straw, maize or cotton stalks, cobs or prunings at 10 to 15 % moisture (12 % in CCB-CAL-001), packed to about 120 kg/m³; about 18.2 MJ/kg dry and 16.0 MJ/kg air-dry (higher heating value).
- Start-up fuel: air-dry wood at about 16.2 MJ/kg (lower heating value), preferably from residues or prunings.
- Char: about 20 MJ/kg and about 55 % organic carbon with about 29 % ash for mixed straw and stalks ([IPCC 2019](https://www.ipcc-nggip.iges.or.jp/public/2019rf/pdf/4_Volume4/19R_V4_Ch02_Ap4_Biochar.pdf) defaults are 49 % for rice straw char and 65 % for herbaceous material).
- One batch a day for about 250 days a year.
- Ambient 10 to 40 °C, dry weather, wind below about 5 m/s.
- The kiln serves a household's or a trial plot's residue, not a whole field (see CCB-PRB-001, out of scope).

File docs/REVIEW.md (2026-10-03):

# Review note: CharCube

## Session 2026-09-25: /populate to a strong TRL 2

### What was done

- `docs/01-problem.md` (CCB-PRB-001 v0.2): problem with cited scale, health and carbon figures; users; constraints; out of scope (including the field-scale gap); prior work (Adam retort, retort field emissions, Kon-Tiki kilns, IPCC permanence factors) with inline sources; open questions; co-design checklist added.
- `docs/03-requirements.md` (CCB-REQ-001 v0.2): 12 measurable requirements (R1 to R12) with targets, a status column against the concept estimates, a list of requirements not met and the assumptions.
- `docs/02-concept.md` (CCB-PRC-001 v0.2): how it works, numbered components, first-order numbers (batch, yield, energy, draft, hot water, carbon, methane, mass, cost), design choices, safety, open questions.
- `cad/src/concept_media.py`: massing model of the nested drums, lid, burner throat, secondary air manifold, flue, water jacket, tap, tripod, insulation, plinth and logger, each with a BOM number; 1.75 m scale figure.
- `media/`: `hero.png`, `concept-blueprint` (PNG, PDF, SVG), `cutaway.png`, `exploded.png` with BOM callouts, `flow.png` (energy per batch, estimates), `model.glb` and `viewer.html`. Temporary view folders removed.
- `bom/bom.csv` (14 lines, numbered to match the exploded view, indicative USD prices) and `bom/bom-notes.md`.
- `README.md`: hero image and links line before "## Problem"; problem, concept, key components and safety text brought in line with the concept.
- `docs/pdf/`: branded PDFs of the three controlled documents.
- `project.yaml` unchanged. The pitch and problem remain accurate.

### Key results (estimates, to be checked at TRL 3)

| Quantity | Estimate | Requirement |
| --- | --- | --- |
| Feed per batch | about 12 kg packed residue; about 4 kg if loose chopped straw | R1 met for packed feed, **not met** for loose straw |
| Biochar yield | about 28 % (20 to 35 %), about 3.4 kg per batch | R2 at risk |
| Start-up wood | about 5 kg | R8 at the limit |
| Batch time | 2.5 to 3.5 h burning, 10 to 14 h sealed cooling | R5 met |
| Heat released | about 180 MJ per batch, about 17 kW average | |
| Hot water | about 15 MJ (10 to 25 MJ); 60 L raised about 60 K | R6 met; may boil on a hot batch |
| Carbon stored for 100 years | about 5.4 kg CO₂ per batch (IPCC medium-temperature factor) | |
| Methane penalty | about 2.3 kg CO₂e per batch at the retort field average | R4 **not shown** |
| Net removal | about 3 to 5 kg CO₂e per batch; about 0.8 to 1.4 t CO₂e a year at 250 batches | |
| Height and mass | about 2.7 m to the rain cap; about 85 kg dry; tripod, jacket and flue unit about 36 kg | R11 met only with a two-person lift |
| Parts cost | about $299 | R10 met with about $1 margin, safety equipment excluded |

Requirements not met or not yet shown:

- **R1 not met for loose chopped straw** (about 4 kg per batch). Straw must be bundled or packed, or mixed with stalks.
- **R4 not shown.** Gas routing is closed by design, but methane and smoke need measurement. At the published retort average, methane cancels about 40 % of the carbon benefit, so the burner throat carries much of the climate case.
- **R2, R3 and R8** rest on wide-range estimates.
- **R10** has no margin and excludes about $40 of safety equipment.
- **R11** needs two people to lift the drained tripod unit.
- **Scale.** One kiln handles about 3 t of residue a year, far less than one hectare of rice straw. The design serves a household, a trial plot or a cooperative with several kilns; it does not replace field burning at scale. This is stated in the problem statement.

### Proposed, awaiting Amish

Status update: items 1 to 8 and 10 were decided by Amish, 2026-09-25: go with recommendation (CCB-DDR-001). Item 9 had no recommendation and remains proposed, awaiting Amish.

1. **Heat recovery type (changes a listed component).** The scaffold listed a copper coil heat exchanger. Options: (a) open-vented annular water jacket around the flue, about 60 L; (b) copper coil in the flue feeding a separate tank by thermosiphon (tank about 2 m high) or pump; (c) no heat recovery, saving about $87. Recommendation: (a), because it needs no pump or raised tank and cannot build pressure. The README key components now describe (a) and say it is proposed.
2. **Budget.** Parts are about $299 against $300, excluding about $40 of safety equipment. Options: (a) keep $300 and list safety equipment separately; (b) raise `budget_usd` to $350 to include it; (c) use a clay and ash render in place of the blanket to save about $25 and fit most of the safety kit. Recommendation: (a) for the kiln budget, with the safety kit stated as required in the build notes at TRL 3. `project.yaml` is unchanged.
3. **Kiln type.** Nested-drum retort (recommended) rather than a Kon-Tiki flame-curtain kiln, which is cheaper and needs no start-up wood but is open and cannot feed a water jacket.
4. **Target feedstock.** Bundled straw and mixed stalks and cobs first (recommended); loose straw only with a press, which would be a separate project.
5. **Burner throat with preheated secondary air** in addition to burning in the annulus. Recommendation: include.
6. **Temperature logger as standard** (about $32). Recommendation: include, as the batch record for char quality.
7. **Insulation:** ceramic fibre blanket (recommended for the prototype) or clay and ash render.
8. **Tripod support** for the jacket and flue, lifted aside by two people for loading (recommended), or a swinging arm at extra cost.
9. **First region, residue and partner** for co-design: for example paddy straw in northwest India or maize and cotton stalks in East Africa.
10. **Name.** CharCube is a cylindrical drum kiln. Keep the name, or reshape the concept (for example a cubic frame) to suit it. Recommendation: keep the name; no change made.

SwapCell is not used; the logger runs from a USB power bank.

### Safety concerns

- Fire and burns: surfaces at 300 to 700 °C, hot char for many hours, embers. Outdoors only, 5 m clearance, extinguisher or water at hand, 3 m exclusion circle for children and animals.
- Flammable and toxic gas: carbon monoxide, hydrogen, methane and tar vapor. Opening a hot retort can cause a sudden flare. Never operate in or near enclosed spaces.
- Water jacket: may boil; must stay open-vented and never be connected to plumbing or sealed. Scald risk at the tap.
- Used drums that held fuel, solvent or pesticide can explode when cut and release toxic fumes when heated; galvanized parts release zinc fumes.
- Char dust: fire and inhalation hazard; wet before handling.
- Heavy lifts: the 36 kg tripod unit and a full jacket (about 76 kg, which must never be moved full).

### Problems and notes

- The cutaway shows the water jacket as a solid annulus because it is modelled as the water volume; the flue passes through its centre.
- The legacy `cad/src/model.py` placeholder is untouched (TRL 3 work).
- The GWP100 of 28 for methane is the IPCC AR5 value; AR6 uses about 27 to 30 depending on source. The conclusion does not change.

### Recommended next step

Review this note and the media, then decide items 1 and 2. If approved, run `/advance-trl3` to check the retort heat balance, gas-hole and secondary-air sizing, draft, jacket heat transfer and surface temperatures by calculation, and to produce the parametric model and drawing sheet.

## Session 2026-09-25: TRL 3

Amish reviewed the TRL 2 points on 2026-09-25 and wrote: "proceed with all of your recommendations across all batches. Make sure we don't proceed to TRL 4 on any of them." This session applied that to CharCube and produced the TRL 3 evidence. TRL 4 is on hold by Amish's instruction.

### What was done

- `docs/decisions/0001-trl2-review-decisions.md` (CCB-DDR-001 v0.1): the nine decided items, the cross-cutting approvals (SwapCell items not applicable), and the open items.
- `docs/04-calcs/01-sizing.md` (CCB-CAL-001 v0.1) with `docs/04-calcs/sizing.py` and `docs/04-calcs/results.csv`: batch and char mass balance, charge heating time by conduction, shell loss and surface temperatures, masses and tripod buckling, energy balance and wood demand, draft, gas holes and air sizing, jacket heat transfer, sealed cooling, carbon, logger accuracy and cost, in three scenarios. The script reads `cad/src/model.py` and `bom/bom.csv`.
- `cad/src/model.py`: parametric build123d model (all key dimensions in `PARAMS`), exporting `cad/step/` and `cad/stl/` `charcube-assembly`, `charcube-kiln`, `charcube-heat-recovery-unit` and `charcube-retort`.
- `cad/src/sheets.py` and `cad/drawings/CCB-DWG-001` (SVG, PDF, PNG): general arrangement at Rev P1, 1:30, "PRELIMINARY, NOT FOR FABRICATION". The concept sheet keeps CCB-DWG-010.
- `bom/bom.csv`: 14 lines, all priced by supplier type, total $298; `bom/bom-notes.md` lists the required safety kit ($40) outside the budget.
- `cad/src/concept_media.py` now builds from the model; all media refreshed (hero, blueprint, cutaway, exploded, flow, GLB viewer) and checked by eye. Temporary view folders deleted.
- CCB-PRB-001, CCB-PRC-001 and CCB-REQ-001 moved to v0.3 with the decisions and CCB-CAL-001 numbers; `README.md` updated; `project.yaml` set to `trl: 3`, `trl_target: 3` with the evidence list.

### Requirements (CCB-CAL-001, central estimates)

5 met, 3 at risk, 1 not verifiable at TRL 3, **3 not met**.

| ID | Status | Value | Target |
| --- | --- | --- | --- |
| R5 | **Not met** | Burn 4.5 h (3.4 to 7.0 h); unload about 8 h after lighting | 4 h; 16 h |
| R6 | **Not met** | 6.4 MJ into water (4.9 to 9.2 MJ), about 25 K rise | 10 MJ |
| R8 | **Not met** | 5.8 kg wood (2.9 to 13.9 kg); light-up alone 1.7 kg | 5 kg |
| R2 | At risk | 28 % yield (20 to 35 %), 2.96 kg char | 25 % |
| R3 | At risk | Core at 450 °C about 4.0 h after lighting | 450 °C, 30 min |
| R9 | At risk | ±3.4 °C to 700 °C with class 1 probes; amplifier unspecified above 700 °C | ±5 °C to 1,000 °C |
| R4 | Not verifiable at TRL 3 | Gas route closed; draft 16.9 Pa, margin 3.2; throat holes 27.1 cm² against 23.6 needed | CH₄ below 24 g/kg |
| R1, R7, R10, R11, R12 | Met | 12.0 kg batch; open jacket; $298; lift 21.6 kg each for two; outlet 2.70 m | |

Other key numbers: heat released 190 MJ per batch; shell loss 5.7 kW (blanket surface 125 °C, bare lid 257 °C); kiln about 91 kg dry; net removal 2.8 kg CO₂e per batch, about 0.70 t CO₂e a year.

Numbers that changed from TRL 2: char 3.4 to 2.96 kg (ash now carried in the char, and 12 kg is air-dry, not dry); hot water about 15 to 6.4 MJ (a plain sleeve gives about 4 to 5 W/m²K, not 15); burn 2.5 to 3.5 h to about 4.5 h; wood 5 to 5.8 kg; draft 19 to 16.9 Pa; lift unit 36 to 43 kg; cost $299 to $298. The 25 mm secondary air ring would have needed about 46 Pa against about 8 Pa available, so the model uses an air shroud.

### Decisions recorded (CCB-DDR-001)

Decided by Amish, 2026-09-25, go with recommendation: (1) open-vented annular water jacket; (2) keep `budget_usd: 300` for kiln parts, safety kit required and separate (budget kept; its scope is written into R10); (3) nested-drum retort; (4) bundled straw and mixed stalks and cobs first (R1 redefined); (5) burner throat with preheated secondary air; (6) logger as standard; (7) ceramic fibre blanket; (8) tripod support; (10) keep the name. Pitch and problem lines had no recommended rewording and are unchanged. Cross-cutting SwapCell items do not apply (no SwapCell pack).

### Still awaiting Amish

- Item 9: first region, residue and partner (no recommendation; partners are chosen per area later).
- Item 11: accept the air shroud in place of the 25 mm ring (recommended). Decided by Amish, 2026-09-25: go with recommendation (CCB-DDR-002).
- Item 12: R6 shortfall. Recommended: spiral baffle insert plus a jacket blanket (about 13.9 MJ on paper, about $15), or relax R6 to 5 MJ, or drop the jacket. Decided by Amish, 2026-09-25: go with recommendation (CCB-DDR-002).
- Item 13: R8 shortfall. Recommended: blanket the lid (about $6, saves about 1.4 kW) and keep the 5 kg target until batches are logged. Decided by Amish, 2026-09-25: go with recommendation (CCB-DDR-002).
- Item 14: R5 shortfall. Recommended: relax R5 to 5 h. Decided by Amish, 2026-09-25: go with recommendation (CCB-DDR-002).
- Item 15: restate R9 as ±5 °C to 700 °C and indicative above. Decided by Amish, 2026-09-25: go with recommendation (CCB-DDR-002).
- Item 16: the safety kit requirement lives in R10 and the BOM notes, not in build notes (which are TRL 4). Decided by Amish, 2026-09-25: go with recommendation (CCB-DDR-002).
- Items 12 and 13 together would take the BOM over $300 unless a line is cut.

### Safety concerns

- Fire, hot surfaces (125 to 260 °C average outside, hotter locally) and hot char for hours; flammable, toxic pyrolysis gas; flare risk if opened hot.
- The jacket must stay open-vented. It does not boil with the plain sleeve, but it could with a baffle insert on a long burn.
- Tar and condensate will deposit on the jacket sleeve, which runs far below the tar dew point.
- Two-person lift of the 43 kg unit near hot steel; a full jacket (83 kg) must never be moved.
- Used drums, no galvanized parts, char dust and blanket fibres (dust mask).

### Problems and notes

- No TRL 4 material exists in the repo; `build-log/README.md` is the kit scaffold and was not extended. Firmware is not started.
- Citations: the TRL 2 note listed no unchecked citations. New sources in CCB-CAL-001 (Channiwala and Parikh 2002; the MAX31855 datasheet) were found by web search; the IEC 60584 thermocouple tolerances used in section 10 are quoted from general knowledge and were not checked against the standard.
- The heating-time model (a solid bed with fixed conductivity) is the largest uncertainty; it drives R3, R5 and R8.

### Recommended next step

Decide items 11 to 16, above all whether to relax R5, R6 and R8 or add the lid blanket and jacket insert. Any design change can be re-run through `sizing.py` and the model at TRL 3. TRL 4 is on hold by Amish's instruction. For reference only, TRL 4 would need: a built kiln, weighed and logged batches (core temperature, wood, char yield, water temperature), lab analysis of the char (H/Corg), smoke and ideally methane measurement with a partner lab, a test report (TST, `environment: lab`) and build log entries.

## Session 2026-09-25: recommendations accepted

Amish wrote on 2026-09-25: "i accept all your recommendations, go with them across all repos." Every open item with a recommendation is now decided by Amish, 2026-09-25: go with recommendation. They are recorded in `docs/decisions/0002-recommendations-accepted.md` (CCB-DDR-002 v0.1). TRL 4 remains on hold by Amish's instruction.

### Decisions applied and what changed

| # | Decision | Change in the repo | Before | After |
| --- | --- | --- | --- | --- |
| 11 | Air shroud in place of the 25 mm ring | Wording only; throat air holes raised to keep up with the baffle's resistance | 24 holes, 27.1 cm² (23.6 needed) | 30 holes, 33.9 cm² (28.5 needed) |
| 12 | Spiral baffle insert and jacket blanket | New parts 15 and 16 in the model, BOM ($7 and $8), drawing and media | Hot water 6.4 MJ, 25 K rise; R6 not met | 11.5 MJ (9.0 to 19.1), 45 K rise; R6 at risk |
| 13 | Lid and top band blanket, R8 target kept at 5 kg | New part 17 in the model, BOM ($6), drawing and media | Shell loss 5.69 kW; wood 5.8 kg; R8 not met | 4.47 kW; wood 3.7 kg (1.7 to 9.8); R8 at risk |
| 14 | Relax R5 to 5 h | CCB-REQ-001 R5 | Target 4 h; not met | Target 5 h; burn 4.5 h (3.4 to 7.0); at risk |
| 15 | Restate R9 to ±5 °C to 700 °C, indicative above | CCB-REQ-001 R9 | At risk | Met (±3.4 °C) |
| 16 | Safety kit stated in R10 and BOM notes, not build notes | CCB-REQ-001 R10 and `bom/bom-notes.md` wording | | |

Knock-on numbers (central): BOM 14 lines $298 to 17 lines $319; draft 16.9 to 16.7 Pa and margin 3.2 to 2.4; kiln 91 to 96 kg; lift unit 43.3 to 46.6 kg (23.3 kg each for two); heat released 190 to 160 MJ; sealed cooling 3.2 to 3.6 h; unfavourable hot water 19.1 MJ against 20.6 MJ to boiling.

Files changed: `cad/src/model.py` (parts 15 to 17, `N_AIR_HOLES` 30; STEP and STL re-exported), `cad/src/sheets.py` and `cad/drawings/CCB-DWG-001` (Rev P1 to P2), `cad/src/concept_media.py` and `media/` (concept sheet CCB-DWG-010 Rev P2; hero, blueprint, cutaway, exploded, flow, GLB viewer regenerated and checked by eye; temporary view folders deleted), `bom/bom.csv`, `bom/bom-notes.md`, `docs/04-calcs/sizing.py` and `results.csv` (re-run), CCB-CAL-001 v0.1 to v0.2, CCB-REQ-001 v0.3 to v0.4, CCB-PRC-001 v0.3 to v0.4, CCB-DDR-001 v0.1 to v0.2, new CCB-DDR-002 v0.1, `README.md` (concept numbers, key components and the four new write-up sections), `project.yaml` (DDR-002 added to the TRL evidence). `budget_usd` stays at 300 and `trl: 3`, `trl_target: 3` are unchanged. The pitch and problem lines had no recommended rewording and are unchanged. CCB-PRB-001 did not attribute the idea to any review session and is unchanged. All PDFs, drawings and media were re-rendered so none shows the old personal-site domain.

### Requirement status (CCB-CAL-001 v0.2, central estimates)

1 not met, 5 at risk, 1 not verifiable at TRL 3, 5 met.

| ID | Status | Value | Target |
| --- | --- | --- | --- |
| R10 | **Not met** | $319 | $300 kiln parts |
| R2 | At risk | 28 % (20 to 35 %), 2.96 kg | 25 % |
| R3 | At risk | Core at 450 °C about 4.0 h after lighting | 450 °C, 30 min |
| R5 | At risk | Burn 4.5 h (3.4 to 7.0 h) | 5 h (relaxed) |
| R6 | At risk | 11.5 MJ (9.0 to 19.1 MJ) | 10 MJ |
| R8 | At risk | 3.7 kg (1.7 to 9.8 kg) | 5 kg |
| R4 | Not verifiable at TRL 3 | Draft margin 2.4; 30 throat holes with 19 % spare area | CH₄ below 24 g/kg |
| R1, R7, R9, R11, R12 | Met | 12.0 kg batch; open jacket; ±3.4 °C to 700 °C; 23.3 kg each for two; outlet 2.70 m | |

### Still awaiting Amish

- Item 9: first region, residue and partner (no recommendation; partners are chosen per area later).
- Item 17 (new), **decided by Amish, 2026-09-26: budget top-up to $320** (see Session 2026-09-26 below): R10 is over budget after items 12 and 13 ($319 against $300). Options: (a) raise `budget_usd` to $320 for kiln parts; (b) cut a line, for example clay and ash render instead of the side blanket; (c) drop the jacket blanket. Recommendation: (a), since (b) and (c) undo part of a decided item. Not applied, because raising a budget needs Amish's decision.

### Cross-repo actions

None. CharCube does not use SwapCell or any other portfolio module, and no decision here needs a change in another repo.

### Safety concerns

- The baffle and jacket blanket bring the water close to boiling on a long burn (19.1 MJ against 20.6 MJ). The vent must never be closed and the jacket must be kept at least three-quarters full.
- Tar and soot collect on the baffle; it lifts out with the flue only when cool.
- The lid blanket must stay clear of the air shroud intake, or the throat will starve of secondary air.
- The lift unit is now 46.6 kg (23.3 kg each for two people), close to the 25 kg per person limit.
- Ceramic fibre and mineral wool need a dust mask when cut.

### Problems and notes

- The factor of 3 on gas-side convection and the 4 velocity heads of loss for the baffle insert are assumptions, not sourced figures; they need measurement.
- The lid blanket saves 1.22 kW, a little less than the 1.4 kW estimated in CCB-CAL-001 v0.1, because the lid under the shroud stays bare.
- The 30-hole throat is a consequence of item 12, not a separate decision; it is recorded in CCB-DDR-002 under item 11.

### TRL 4

TRL 4 remains on hold by Amish's instruction. No build, test, purchase, PCB or firmware work was done. For reference, TRL 4 would measure the baffle's heat transfer and fouling, wood use, char yield and emissions on logged batches.

### Recommended next step

Decide item 17 (budget); decided 2026-09-26. Item 9 stays open until co-design partners are chosen per area.

## Session 2026-09-26: sources strengthened

Amish asked on 2026-09-26 to "fix the weaker sources" and wrote "I am ok with the budget top ups."

### Sources replaced

| Item | Old source | New source |
| --- | --- | --- |
| Brazil (São Paulo) row | Instituto Escolhas article (NGO summary) | Text of State Law 11,241 of 2002 on the Assembleia Legislativa do Estado de São Paulo site, plus the state Instituto de Economia Agrícola (2014) for the 2021 and 2031 deadlines, which the row now states |
| United States (California) row | FindLaw copy of Health and Safety Code 41865 | Statute text as published by the Glenn County Air Pollution Control District (subdivisions (c)(4) and (i): 25 % of planted acres from 2001) |
| East Africa row and What sparked the idea | IDEAS/RePEc listing of Adam (2009) | Publisher DOI 10.1016/j.renene.2008.12.009 (Elsevier, *Renewable Energy* 34(8)); also in CCB-PRB-001 (v0.3 to v0.4) |
| Kenya and East Africa row | Uncited "maize and cotton stalks" claim | Row renamed East Africa and limited to what Adam (2009) supports (pilot units in East Africa) |
| Vietnam and Southeast Asia row | Van Hung et al. (2020), kept | Row renamed Southeast Asia and reworded to what the chapter supports (100 to 140 Mt of straw a year in the region, short turnaround, burning despite bans) |
| Europe row | "(Switzerland, Germany)" uncited | Label shortened to Europe; European Biochar Certificate link kept |
| What sparked the idea | "masonry kiln ... surplus heat goes to waste" not in the source | Replaced by "It was built for wood charcoal" |

Checked and kept: Lan et al. (2022, *Nature Communications*), the WHO ambient air quality fact sheet, Sparrevik et al. (2015, *Biomass and Bioenergy*) and Van Hung et al. (2020). The European Biochar Certificate page is the program's own site; it could not be re-fetched this session. The inspiration event (Adam retort) is unchanged, now linked to the publisher's DOI.

### Budget change

Budget top-up to $320: decided by Amish, 2026-09-26 (CCB-DDR-002 v0.2, item 17). `project.yaml` `budget_usd` 300 to 320. `docs/04-calcs/sizing.py` now reads the budget from `project.yaml`; re-run, `results.csv` updated. R10 is met with a $1 margin ($319 against $320); requirement status is now 6 met, 5 at risk, 1 not verifiable at TRL 3, none not met. Documents: CCB-REQ-001 v0.4 to v0.5, CCB-CAL-001 v0.2 to v0.3, CCB-PRC-001 v0.4 to v0.5, CCB-DDR-002 v0.1 to v0.2, CCB-PRB-001 v0.3 to v0.4 (sources). README budget line and concept paragraph updated; `bom/bom-notes.md` updated. The budget note on CCB-DWG-001 and the key figures on the concept sheet CCB-DWG-010 were updated in `cad/src/sheets.py` and `cad/src/concept_media.py` (both Rev P2 to P3) and all drawings and media regenerated; temporary view folders deleted. `trl: 3` and `trl_target: 3` unchanged.

## Session 2026-09-26: product appearance model and photoreal renders

Amish chose this repo for the first batch of product renders on 2026-09-26. This session adds an appearance model for photoreal renders; no design, sizing or BOM content changed.

### What was done

- `cad/src/product_model.py` (new): `product_parts()` returns 49 parts (47 product parts in the shell and internal groups, 2 context parts) with colour, material, BOM line, group and explode offset, plus `TITLE` and `RENDER_VIEWS` (hero, exploded and a detail view without the ground and person). It imports `PARAMS`, `levels()` and `build_parts()` from `cad/src/model.py`, so every main dimension, height and interface is unchanged. It adds:
  - outer drum chimes and rolling hoops, and sliding port dampers with knobs on the four primary air ports;
  - the drum blanket with a wire mesh, overlap flap, a teal name band and a hot-surface label; the lid blanket with tie wires;
  - riveted lid collar with a rolled edge, a band damper handle on the air shroud, a rolled flue outlet and a conical rain cap on the three posts;
  - the water jacket painted in the kit accent, with its loose lid, open vent rim, mineral wool blanket with tie wires and a second hot-surface label, and a brass ball-valve tap with a lever;
  - tripod legs drawn as 40 x 40 x 4 mm angle on a flat-bar ring seat, with bolted gussets, foot plates and ground pins;
  - retort rolling hoops, lid swages and a bolt-ring clamp bolt; chamfered firebricks; block joints and an ash pan lip on the plinth;
  - the logger as a weatherproof box with a clear window over its board, modules and power bank, a lit green status light, cable glands, straps to the leg, probe cables and type K probes;
  - context: a compact paved ground patch and the shared clay mannequin (1.75 m, "stand") beside the kiln.
- `README.md`: hero image now `media/render-hero.png`, with a link to `media/render-exploded.png`. The render files are produced later by the orchestrator.
- Self-check previews (matplotlib, clear parts omitted) were made outside the repo.

### Differences from model.py

Each is an appearance choice only; model.py, the drawing and the BOM are unchanged.

1. **Rain cap shape.** model.py draws a 260 mm square plate; the appearance model draws a 260 mm conical cap on the same three posts at the same height. Proposed, awaiting Amish. Recommendation: adopt the conical cap in model.py and CCB-DWG-001 at the next model update, since the BOM does not fix the shape and a cone sheds rain better.
2. **Tripod leg and ring seat sections.** model.py draws round stand-ins (28 mm round legs and a 20 mm round ring seat); the appearance model draws the BOM section: 40 x 40 x 4 mm angle legs, a flat-bar ring seat just under the jacket, and bolted gussets. Foot and top points are unchanged. Proposed, awaiting Amish. Recommendation: carry the angle section into model.py so drawings and renders agree.
3. **Logger position.** model.py centres the logger box on the tripod leg, so the leg passes through it; the appearance model puts the box on the front face of the same leg, 62 mm toward -Y, strapped to it, at the same height. Proposed, awaiting Amish. Recommendation: move the box in model.py to the same position.
4. **Tap lever.** model.py draws the handle as a 90 mm bar above the valve; the appearance model draws a ball-valve lever across the pipe (closed position) at the valve body. Proposed, awaiting Amish. Recommendation: keep the model.py envelope for drawings; no action needed.
5. **Added detail not in model.py** (port dampers, name band, hot-surface labels, rivets, bolts, logger internals, straps): all belong to existing BOM lines (1, 13 and 14). The name band and labels are not priced in the BOM. Proposed, awaiting Amish. Recommendation: add hot-surface labels to line 14 (hardware and consumables) when the BOM is next revised; they cost little and support the safety section.

### Safety

The renders show hot-surface labels on the drum blanket and the jacket blanket and the open, uncapped jacket vent, consistent with the safety section of the design precis. They are illustrative; the labels are not a specified safety sign set.

### TRL

This is an appearance model only, with no tolerances or fabrication detail. `trl: 3` and `trl_target: 3` are unchanged, and TRL 4 remains on hold by Amish's instruction.

## Session 2026-09-27: kit 1.5.0 and image quality

- Kit 1.5.0 synced: STANDARDS v1.5 (sections 12 to 15: product renders, storefront images and image quality, public release, authorship and signing), `.kit/cards.py`, `.kit/image_qc.py`, `.kit/release_gate.py`, issue templates, and the `/render-product` and `/release` commands. `CLAUDE.md` now matches `.kit/CLAUDE.md`.
- Every `media/render-*.png` recaptioned from its original render with the new layout: the title, concept label and repository sit in a band above the render and the view note in a band below it, each line wrapped to the image width, so no text overlaps other text or the render or runs off the image. `media/card.png` and `media/social-preview.png` regenerated with the same rules.
- `python .kit/image_qc.py` and `python .kit/release_gate.py` pass. trl stays 3.

## Session 2026-09-30: design made constructable and prototype build plan (kit 1.7.0)

### What was done

- Kit 1.7.0 installed (`.kit/`, `.claude/commands/`); `CLAUDE.md` now matches `.kit/CLAUDE.md`.
- Constructability review of every component with build123d. `cad/src/model.py` now builds each component as it is made and fitted (`build_components()`) and runs 68 checks of contacts, clearances and overlaps (`python cad/src/model.py --check`): 68 of 68 pass. STEP and STL regenerated.
- `docs/decisions/0003-design-for-construction.md` (CCB-DDR-003 v0.1, Draft): twelve changes, made under Amish's 2026-09-30 instruction to make the design physically buildable; open for his review.
- `docs/05-build-plan.md` (CCB-BLD-001 v0.1): the illustrated prototype build plan, 21 components in build order, 19 assembly steps, first checks, safety stops. Pictures from `cad/src/build_plan_media.py`: overview, 14 making sketches (`cad/drawings/CCB-DWG-101` to `114`), 11 joint close-ups and 19 step pictures in `docs/05-build-plan/`.
- `docs/06-design-decisions.md` (CCB-DEC-001 v0.1): open decisions, items to confirm when parts are bought, and decisions made.
- Calculations re-run: CCB-CAL-001 v0.4 (`docs/04-calcs/sizing.py` now takes the tripod geometry from the model). CCB-PRC-001 v0.6, CCB-REQ-001 v0.6, `bom/bom.csv` and `bom/bom-notes.md` updated. CCB-DWG-001 Rev P5; concept sheet CCB-DWG-010 Rev P4; concept media and `media/model.glb` regenerated.
- `project.yaml`: `design_state: constructable`; the build plan, the register and CCB-DDR-003 added to `trl_evidence`. README: links line and a "Building the prototype" section.

### Design changes made for construction (CCB-DDR-003)

1. Plinth blocks laid as a pinwheel, 580 mm square (they overlapped by 50 mm).
2. Lid hole 150 mm; the throat stands on the lid inside a collar rolled to fit it, riveted to the lid by six tabs and to the throat by four rivets (the throat could drop through the 160 mm hole).
3. Air shroud riveted to the throat by six tabs; band damper 60 mm with a wing screw (no fixing; the band floated and could not close the intake).
4. Port dampers modelled as curved plates sliding in riveted guide strips (listed but not drawn or held).
5. Firebricks laid round the retort's edge, 200 mm out, 8 mm clear of the gas holes (they covered gas holes).
6. Two M8 U-bolt handles on the retort lid (no way to lift the retort out of a 43 mm gap).
7. Jacket stand: three fins welded to the jacket, angle legs bolted flat to them, pinned at bolted foot cleats and pads; ring seat removed (the ring was 7 mm below and outside the jacket, so nothing carried it).
8. Flue 650 mm on three stop clips resting on the sleeve rim; rain cap on three riveted legs, 60 mm above the outlet (no seat for the flue; cap posts inside the bore; cap 10 mm above the outlet at 2.75 m).
9. Baffle hung on a 10 mm rod through the flue foot (the cross bar cut into the flue wall).
10. Jacket loose lid resting on the rim on three tabs, with a 210 mm centre hole and the vent nipple through it (lid and vent floated).
11. Logger box strapped beside the leg (the leg passed through it).
12. Core probe 500 mm in through the drum side and a retort slot; throat probe below the sleeve (the probe could not be inserted or reach the core).

### Key results

- Masses (CCB-CAL-001 v0.4): kiln 97 kg (was 96 kg); lift unit 47.4 kg, 23.7 kg each for two (was 46.6 kg); retort with char 15.5 kg; full jacket 85 kg. R11 still met with 1.3 kg per person to spare. Tripod leg buckling factor 58.
- Flue outlet stays 2.70 m. Draft margin 2.4, secondary hole area 33.9 cm² against 28.6 cm² needed. Heat to water unchanged at 11.5 MJ.
- No requirement changed status: six met, five at risk (R2, R3, R5, R6, R8), one not verifiable at TRL 3 (R4). R10 is within the $320 value-engineering target only on the unchanged prices ($319 estimated); the added parts are not priced.

### Proposed, awaiting Amish

All in the design decisions register (CCB-DEC-001): accept CCB-DDR-003 (1); concrete blocks under the hot drum floor (2); flared sleeve bottom to guide the jacket onto the throat (3); two-person lift or a swinging arm (4); first region and partner (5); conical rain cap (6); hot-surface labels in the BOM (7). The register's Value engineering section holds the $320 target, the $319 estimate and the savings worth trying.

### Safety concerns

- The plinth's concrete blocks sit under the fire below the retort; their temperature is a first check.
- Lowering the 47 kg heat-recovery unit onto the throat with 2 mm clearance at about 1.5 m is the hardest handling step; it needs two people and a drained jacket.
- Both probes must be pulled out before the retort or the heat-recovery unit is moved.

### Stale media

The photoreal renders (`media/render-*.png`), `media/card.png`, `media/social-preview.png` and `cad/src/product_model.py` still show the concept's ring seat, round rain cap posts and the logger through the leg. They are made on Amish's Mac and were not regenerated here.

### TRL

`trl: 3`, `trl_target: 3`. The build plan is TRL 3 paper work; nothing was built, bought or tested. TRL 4 remains on hold by Amish's instruction.

### Recommended next step

Amish to review CCB-DDR-003 and decide the open items in CCB-DEC-001; then refresh the photoreal renders on the Mac.

## Session 2026-10-02: open decisions decided by Amish

Authority: Amish, 2026-10-02: "i approve your recommendations for all 555 open decisions." The recommendations approved are those written for the open decisions in the design decisions register. No model, BOM quantity or price, or picture was changed; where a decision needs one, it is listed below as a follow-up. `trl` and `trl_target` stay at 3. No commit or push.

### Decisions recorded

7, all moved to "Decisions made" in `docs/06-design-decisions.md`, dated 2026-10-02:

1. Design for construction (CCB-DDR-003) accepted: all twelve changes, with the first burn to confirm that the 150 mm lid hole does not limit draft.
2. Plinth: 25 mm ceramic fibre board between pan and blocks from the first burn, with a thermocouple on a block; dropped later only if a measured burn keeps the blocks under about 150 °C.
3. Jacket sleeve: bottom 20 mm flared to about 190 mm.
4. Heat-recovery unit: a lifting aid (swinging arm on a post or hand winch) designed for the first build; users asked how it should work.
5. First region, residue and partner: selection rule set (open straw burning, partner already running residue or biochar trials); first candidate to approach an agricultural university extension service such as Punjab Agricultural University.
6. Rain cap: conical cap adopted in the model and drawings.
7. Hot-surface labels (ISO 7010 W017) for the drum blanket and jacket added to BOM line 14.

### Documents changed

- `docs/06-design-decisions.md` (CCB-DEC-001 v0.3)
- `docs/decisions/0003-design-for-construction.md` (CCB-DDR-003 v0.3): accepted; A2 and A3 recorded; status stays Draft
- `docs/02-concept.md` (CCB-PRC-001 v0.8): lifting aid, fibre board, labels, conical cap, partner rule
- `docs/03-requirements.md` (CCB-REQ-001 v0.8): R11 note on the lifting aid
- `bom/bom.csv`: notes on lines 7, 12 and 14 only; no quantity or price changed

### Follow-up actions to carry approved decisions into the design

1. Decision 2 (model): Add the 25 mm ceramic fibre board between the ash pan and the blocks in `cad/src/model.py` and check the raised kiln (port height, flue outlet height, contacts); regenerate CCB-DWG-001 and the plinth making sketch.
2. Decision 2 (pictures): Show the fibre board and the block thermocouple in build plan section 3.1 and its first checks.
3. Decision 2 (bom): Add the fibre board to the BOM line 12 spec and price, and a block thermocouple to line 13.
4. Decision 3 (model): Flare the bottom 20 mm of the jacket sleeve to about 190 mm in the model, the jacket making sketch and build plan section 3.11, step 15.
5. Decision 4 (model): Design the lifting aid (a swinging arm on a post or a hand winch) for the heat-recovery unit in the model and drawings.
6. Decision 4 (pictures): Show the lifting aid in build plan sections 3.15 and 3.16.
7. Decision 4 (bom): Add the lifting aid to the BOM with a price.
8. Decision 4 (calcs): Check the lifting aid's loads and re-judge R11 and R10 in CCB-CAL-001.
9. Decision 6 (model): Model the conical rain cap on the three flat-bar legs and 60 mm gap; regenerate CCB-DWG-001, the flue making sketch and build plan section 3.18; update the BOM line 7 spec.
10. Decision 7 (bom): Add the hot-surface warning labels to the BOM line 14 spec and price, and show them in build plan section 3.21.
11. Decision 1 (calcs): Price the parts added for construction and the additions decided on 2026-10-02, and re-state the value-engineering result in CCB-CAL-001, section 11.

### Points found in the review

- Value engineering is not like for like: the USD 319 estimate leaves the parts added for construction unpriced (about USD 5 to 10), and items 2, 4 and 7 as recommended add more. Price them before reading the result against the USD 320 target.
- R11 (no lift above 25 kg per person) ignores lift height and the reduced capacity of team lifts; the 47 kg unit lifted to about 1.5 m meets the letter of R11 but not common manual-handling guidance.
- The register still describes the rain cap as resting on 'posts'; the design for construction replaced them with three riveted flat-bar legs.

## Session 2026-10-02: Approved follow-ups carried out

Authority: Amish, 2026-10-02: "497 follow-up actions that need CAD, drawing, picture, BOM or calculation work ... APPROVED CHANGES, COMPLETE THESE", and "Photoreal renders are out of date in most repos ... COMPLETE THESE" (render scenes prepared here; photoreal images, `media/card.png` and `media/social-preview.png` are made on Amish's Mac). `trl` and `trl_target` stay at 3. No commit or push.

### Follow-ups

1. Decision 2 (model): done. A 600 x 600 x 25 mm ceramic fibre board now lies between the blocks and the pan, with a groove in its underside for the block thermocouple. The kiln rises 25 mm: drum floor 218 mm, air ports clear of the board by 13 mm, flue outlet 2.72 m (was 2.70 m), kiln 2.84 m to the top of the cap; all contacts re-checked. CCB-DWG-001 (Rev P6) and the plinth making sketch CCB-DWG-101 regenerated.
2. Decision 2 (pictures): done. Build plan section 3.1, Figures 2 and 3 (joint 1), step 1 and the first checks (block temperature from the block thermocouple, logger check on three channels).
3. Decision 2 (BOM): done. Line 12 $12 to $40 (board $28); line 13 $32 to $42 (bare-wire type K and a third amplifier, $10).
4. Decision 3 (model): done. The bottom 20 mm of the jacket sleeve is a cone flaring to 190 mm; CCB-DWG-108, joint 5 and build plan section 3.11 (and step 15) updated. Two 18 mm lift-bar holes added to the top socket for item 5.
5. Decision 4 (model): done. Lifting aid designed and modelled (BOM line 18): a post of 88.9 x 3.2 mm tube, 4.0 m above the ground, turning in a ground sleeve in a 600 x 600 x 750 mm footing 1.2 m behind the kiln; a bolted arm of two 50 x 50 x 5 mm angles with a 40 x 40 x 4 mm brace; two pulleys, a 270 kg hand brake winch, 5 mm steel wire rope and a hook; a 16 mm lift bar through the sleeve socket. It raises the drained unit 1.55 m (feet above the throat top), so the unit clears the kiln on any path, and swings it a quarter turn to set it down. New making sketches CCB-DWG-115 and CCB-DWG-116; shown on CCB-DWG-001.
6. Decision 4 (pictures): done. Build plan new section 3.22 (Figures 28 to 31, joints 12 and 13), notes in sections 3.15 and 3.16, step 15 picture and text, step 18, safety stop S4, first checks, tools and workspace.
7. Decision 4 (BOM): done. Line 18, $160, priced item by item in its notes.
8. Decision 4 (calcs): done. CCB-CAL-001 section 4, Table 4a: post stress factor 4.3 on yield, top deflection about 46 mm, arm factor 4.1, brace buckling factor 51, lift bar factor 3.2, winch and rope factors 3.8 and 21, footing overturning factor 2.1 by weight alone. R11 re-judged: met, nobody carries the unit; heaviest hand lift the retort with char, 15.5 kg (setting up: post about 16 kg each for two). R10 re-judged: not met.
9. Decision 6 (model): done. Conical cap (260 mm, 30 degree slope, 1.5 mm sheet) on the three flat-bar legs, at least 60 mm from the flue lip; CCB-DWG-001, CCB-DWG-112, CCB-DWG-113, joint 9, build plan section 3.18 and BOM line 7 updated.
10. Decision 7 (BOM): done. Line 14 $15 to $26 (two 100 mm aluminium W017 labels, $8, and $3 of fasteners added for construction); labels modelled at the front right of both blankets and shown in build plan section 3.21 (Figure 27, joint 14).
11. Decision 1 (calcs): done. Every BOM line priced with its basis; CCB-CAL-001 section 11 restated: Value-engineering target: USD 320. Estimated cost of the constructable design: USD 546 (USD 226 over the target). Parts added for construction $17; 2026-10-02 additions $186 (lifting aid $160). `budget_usd` unchanged.

### Requirement status changes

- R10: met to **not met** ($546 against $320).
- R11: stays met, re-judged on the lifting aid (was 23.7 kg each for two people).
- No other change: met 5 (R1, R7, R9, R11, R12), at risk 5 (R2, R3, R5, R6, R8), not verifiable 1 (R4), not met 1 (R10). Outlet 2.72 m; tripod leg factor 56; heat to water and draft unchanged (11.5 MJ; margin 2.4).

### Cost and mass

Estimated cost $546 (18 lines). Kiln 97 kg without plinth and water; heat-recovery unit 47.2 kg (was 47.4 kg, lighter cap); fibre board 2.9 kg; lifting aid post 32 kg and arm, brace, pulleys and winch 23 kg, plus a 621 kg concrete footing.

### Documents changed (new versions)

- `cad/src/model.py`: fibre board, block thermocouple, sleeve flare and lift-bar holes, conical cap, labels, lifting aid; 100 of 100 constructability checks pass (was 68). STEP and STL regenerated, with a new `charcube-lifting-aid` unit.
- `bom/bom.csv` (18 lines, $546) and `bom/bom-notes.md`.
- `docs/04-calcs/sizing.py` and `results.csv`; `docs/04-calcs/01-sizing.md` CCB-CAL-001 v0.6.
- `docs/03-requirements.md` CCB-REQ-001 v0.9; `docs/02-concept.md` CCB-PRC-001 v0.9; `docs/06-design-decisions.md` CCB-DEC-001 v0.4 (Value engineering section); `docs/05-build-plan.md` CCB-BLD-001 v0.2; `README.md`.
- Drawings and pictures: CCB-DWG-001 Rev P6 (now 1:50, footing left off); concept media CCB-DWG-010 Rev P5 (`media/hero.png`, `concept-blueprint`, `cutaway.png`, `exploded.png`, `flow.png`, `model.glb`); build plan overview, all 19 step pictures, joints 1, 5, 9, 12 (new), 13 (new), 14 (new); making sketches CCB-DWG-101, 108, 112, 113, 115 (new), 116 (new).
- `cad/src/product_model.py`: brought to the constructable design (fins, bolted legs and pads, clips, conical cap on legs, pinwheel plinth with board, flared sleeve, logger and probes from the model) with every main dimension from `model.py`; the lifting aid is a new `site` group with a new `site` view (hero, exploded and detail kept). Render scenes exported to `/home/claude/renders/charcube` (hero, exploded, detail, site; `.npz` and `.json` each, and `charcube__jobs.json`).
- `drawing.py --check-text`: no hits.

### Not done

- Asking users through the partner how the lifting aid should work (decision 4): not done: outreach by Amish.
- Photoreal renders, `media/card.png` and `media/social-preview.png`: not done here by instruction; made on Amish's Mac from the exported scenes.

### Cross-repo actions

None.

### Proposed, awaiting Amish

- Whether the lifting aid ($160) counts against the kiln parts target or is site equipment listed beside the safety kit (it can serve several kilns). Recommendation: list it as site equipment; the kiln estimate would then be $386, still $66 over.
- Cheaper alternative to try: a winch hung from an existing strong beam or tree where a site has one.

### Safety

- The unit hangs 1.55 m up while it is swung: S4 now requires the winch only, the flue out first, and nobody under the load. The post's top moves about 46 mm under full load; the first check holds the unit 100 mm up for 5 minutes before a full lift.
- The arm is parked away from the flue during burns.

## 2026-10-02: photoreal renders redone on the constructable design

Rendered with Blender Cycles on Amish's Mac from the updated appearance model; captioned with `.kit/photo_caption.py`; `media/card.png` and `media/social-preview.png` regenerated with `.kit/cards.py`. Views: hero, exploded, site, detail. image_qc passes. Appearance deviations are those logged above as proposed, awaiting Amish.

## 2026-10-03: decisions recorded

Amish decided on 2026-10-03: "Cost over target - i accept all the cost variations and overruns". Recorded for this repo: the estimated cost of USD 546 against the USD 320 target (USD 226 over), with the lifting aid (USD 160) counted in the kit cost as it stands.

- `docs/06-design-decisions.md`: row added to decisions made; value engineering section says the overrun was accepted by Amish on 2026-10-03.

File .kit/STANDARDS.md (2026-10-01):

---
doc_id: OHP-STD-001
title: Documentation and drawing standard
project: Open Hardware Portfolio
doc_type: Standard
version: "1.7"
status: Released
date: 2026-09-30
author: Amish Chadha
license: CC-BY-SA-4.0
revisions:
  - version: "1.0"
    date: 2026-09-24
    author: Amish Chadha
    change: First release of the standard
  - version: "1.1"
    date: 2026-09-24
    author: Amish Chadha
    change: Adopt Technology Readiness Levels (section 9) for project maturity
  - version: "1.2"
    date: 2026-09-24
    author: Amish Chadha
    change: Portfolio phase cap (section 10), concept media standard (section 11), CLAUDE.md guardrails
  - version: "1.3"
    date: 2026-09-24
    author: Amish Chadha
    change: Scale figure, interactive 3D viewer and flow diagrams added to concept media; session slash commands
  - version: "1.4"
    date: 2026-09-26
    author: Amish Chadha
    change: Every sheet and render names the project and its GitHub repository; overall dimensions, ISO centre lines and 300 dpi PNG on sheets; titles name the device and view labels state the viewing direction; optional photoreal renders with Blender
  - version: "1.5"
    date: 2026-09-27
    author: Amish Chadha
    change: Product renders (section 12), storefront images and image quality check (section 13), public release and release gate (section 14), authorship, citation and commit signing (section 15)
  - version: "1.6"
    date: 2026-09-29
    author: Amish Chadha
    change: Licensing metadata with REUSE (section 16), Zenodo DOI and Software Heritage archiving (section 17), release gate checks REUSE and a single CITATION.cff license, archive.py
  - version: "1.7"
    date: 2026-09-30
    author: Amish Chadha
    change: Concept and constructable design states; design decisions register (DEC) kept apart from the build plan; prototype build plan (BLD, section 18) with pictures by component is required TRL 3 evidence; every repo targets TRL 3 during the populate phase; build_views.py; /to-trl3 and /build-plan commands
---

# Documentation and drawing standard

Every project in the portfolio uses this standard, so that each precis, write-up and sketch looks the same and carries its own version history. The standard ships as a kit in each repo's `.kit/` folder. The kit version is in `.kit/KIT_VERSION`.

## 1. Document types and IDs

Every controlled document has a unique ID in the form `PRJ-TYP-NNN`.

- `PRJ` is the three-letter project code listed in section 7.
- `TYP` is the document type code from the table below.
- `NNN` is a sequence number within that project and type, starting at 001.

| Code | Type | Typical file |
| --- | --- | --- |
| PRC | Design precis | `docs/02-concept.md` |
| PRB | Problem statement | `docs/01-problem.md` |
| REQ | Requirements | `docs/03-requirements.md` |
| CAL | Calculation or sizing note | `docs/04-calcs/*.md` |
| DDR | Design decision record | `docs/decisions/*.md` |
| BOM | Bill of materials | `bom/bom.csv` |
| DWG | Drawing or sketch sheet | `cad/drawings/*.svg` |
| BLD | Prototype build plan (section 18) | `docs/05-build-plan.md` |
| DEC | Design decisions register (section 18) | `docs/06-design-decisions.md` |
| TST | Test plan or test report (front matter adds `environment: lab` or `relevant`) | `docs/05-tests/*.md` |

Example: `TBK-PRC-001` is the ThermaBrick design precis.

## 2. Revision scheme

| Artifact | While in draft | When released | Change after release |
| --- | --- | --- | --- |
| Documents | 0.1, 0.2, 0.3 ... | 1.0 | 1.1 for minor edits, 2.0 for a design change |
| Drawings | Rev P1, P2 ... (preliminary) | Rev A | Rev B, C ... |

- Every change to a controlled document adds a row to its revision history before the commit.
- The `version` field in front matter always equals the newest row in `revisions`. The renderer rejects a document where they differ.
- Status is one of `Draft`, `In review`, `Released` or `Superseded`. Draft and In review documents print with a status band on every page.
- Every release is tagged in Git as `<doc_id>/v<version>`, for example `TBK-PRC-001/v1.0`. Drawings are tagged `TBK-DWG-001/revA`.
- Git history is the full audit trail. The in-document revision table is the human-readable summary.

## 3. Document front matter

Every Markdown document under version control starts with this block:

```yaml
---
doc_id: TBK-PRC-001
title: ThermaBrick design precis
project: ThermaBrick
doc_type: Precis
version: "0.1"
status: Draft
date: 2026-09-24
author: Amish Chadha
license: CERN-OHL-S-2.0
revisions:
  - version: "0.1"
    date: 2026-09-24
    author: Amish Chadha
    change: Initial draft
---
```

Quote version numbers so YAML keeps `1.0` as text instead of turning it into a number. List revisions newest last.

## 4. Writing style

- Chicago Manual of Style.
- No em dashes. Restructure the sentence instead.
- Lead each section with its conclusion, then support it.
- SI units throughout, in the form `12 kW`, `450 °C`, `3.2 m`. Imperial values may follow in parentheses.
- Number every figure and table ("Figure 2", "Table 1") and give each a caption.
- State every assumption in the calculation that depends on it.
- Put safety notes in a blockquote starting with **Safety:**.

## 5. Visual identity

| Element | Specification |
| --- | --- |
| Typeface | IBM Plex Sans for text, IBM Plex Mono for code and values (SIL Open Font License, bundled in `.kit/fonts`) |
| Ink | `#111827` |
| Secondary text | `#4B5563` |
| Rules and grid | `#D1D5DB` |
| Accent (one only) | `#0F766E` teal |
| Document page | US Letter, 20 mm margins |
| Drawing sheet | ANSI B landscape (431.8 x 279.4 mm) |
| Footer | Document ID, version, status, license and designmolecule.com on every page |

## 6. Drawing and sketch conventions

- Units are millimeters unless the title block says otherwise.
- Third-angle projection, marked with the symbol in the title block.
- Line weights: visible outlines 0.5 mm, hidden lines 0.25 mm dashed, center lines 0.18 mm chain.
- The title block contains the project, title, drawing number, revision, scale, units, projection, sheet, author, date, material or notes, and license.
- Every sheet and every render names the project and its GitHub repository (from `repo:` in `project.yaml`), at the top of the sheet and in the title block, so a printed or forwarded sheet is never anonymous.
- The drawing title names the device, not only the drawing type (for example "Handheld near-infrared resin scanner: general arrangement").
- Every view label states its scale and viewing direction (for example "Scale 1:1; side elevation looking along +Y"), and every isometric or render states where it is seen from.
- Orthographic views generated with `add_ortho` carry overall dimensions (length and depth on the top view, height on the front view) and ISO 128 centre lines on cylinders; hidden lines are dashed. Tolerances are not shown before TRL 4.
- Sheets are exported as SVG, PDF and a 300 dpi PNG.
- The revision table in the top right of the sheet lists every revision.
- Concept sketches use the same sheet and title block and carry the label "CONCEPT, NOT FOR FABRICATION".
- Geometry comes from `cad/src/*.py` (build123d). Sheets are generated by `.kit/drawing.py` and never edited by hand.

## 7. Project codes

| Code | Project | Code | Project | Code | Project |
| --- | --- | --- | --- | --- | --- |
| TBK | ThermaBrick | PCF | PicoFlow | HLT | HelioLite |
| CCB | CharCube | DRN | DustRunner | TRT | TremorTrace |
| STC | StepCue | FXH | FlexHand | CPD | ColdPod |
| SCL | SunClave | STR | SteamRoot | GGD | GrainGuard |
| SDL | SeedLine | ZBX | ZeerBox | RMS | RootMesh |
| DWD | DewDrive | SSK | StillStack | PPR | PotPress |
| WWT | WaterWatch | LMF | LumaFlow | FCL | FieldCell |
| CNP | ConePro | CVC | CulvertCrawl | EGD | EmberGuard |
| SNF | SnapFrame | CGM | CargoMule | SCM | StepClimber |
| SWC | SwapCell | PLP | PalletPilot | FTK | FlatTrike |
| WWK | WaterWalker | GRR | GrowRider | SSP | SunSpoke |
| SGN | StepGen | PBX | PowerBox | WML | WasteWise-ml |
| WSC | WasteWise Scan | RFE | ReflowEconomy | | |
| OHP | Portfolio-wide | | | | |

## 8. Build and publish

- `python .kit/render.py` checks every controlled document and renders it to `docs/pdf/<doc_id>_v<version>.pdf`.
- `python .kit/drawing.py` (called from each project's `cad/src/sheets.py`) builds drawing sheets as SVG and PDF in `cad/drawings/`.
- The GitHub Action in `.github/workflows/docs.yml` runs the checks on every push and attaches PDFs to a GitHub Release whenever a release tag is pushed.
- Public releases follow section 14: `python .kit/release_gate.py` must pass, and the release tag is `v0.<TRL>.0` (for example `v0.3.0` at TRL 3).

## 9. Technology Readiness Level (TRL)

Each project states its maturity as a Technology Readiness Level on the NASA and US DOE 1 to 9 scale. The TRL rates this specific design, not the underlying technology. A sand battery is commercial elsewhere, but a new sand battery design starts at TRL 2 until evidence shows otherwise.

| TRL | Definition | Evidence the repo must contain |
| --- | --- | --- |
| 1 | Basic principles observed | Problem statement (PRB) |
| 2 | Technology concept formulated | Draft precis (PRC) and requirements (REQ) |
| 3 | Analytical or experimental proof of concept | Calculation note (CAL), working build123d model with STEP export, drawing sheet (DWG), priced BOM with every unit cost filled in, prototype build plan (BLD) with pictures, `design_state: constructable` |
| 4 | Components validated in the lab | Test report (TST) with `environment: lab`, build log entries |
| 5 | Validated in a relevant environment | Test report (TST) with `environment: relevant` |
| 6 | System prototype demonstrated in a relevant environment | Precis at version 1.0 or later with status Released, a drawing at a lettered revision (Rev A or later), and a system-level TST with `environment: relevant` |
| 7 to 9 | Operational demonstration through proven in service | Beyond portfolio scope; claim only with a named deployment partner and evidence |

Rules:

- `project.yaml` records `trl` (current level), `trl_target` (the level the current effort aims for) and `trl_evidence` (the files that support the claim).
- `python .kit/render.py --check` fails if the evidence for the claimed TRL is missing. CI runs this check on every push.
- Documentation alone cannot go past TRL 3. TRL 4 and above require hardware and a test report.
- TRL and visibility are independent. A repo can be public at TRL 3 as a documented design ready to build.
- A change of TRL is recorded in the build log with the date and the evidence that justified it.

## 10. Portfolio phase and TRL cap

`.kit/PHASE.yaml` sets the current phase. During the **populate** phase every repo is capped at **TRL 3**: `trl` and `trl_target` may not exceed 3, and the check fails if they do. Every repo targets the cap: `trl_target` must equal 3, so a new repo is taken all the way to TRL 3 (scaffold, populate and advance, see `/to-trl3`). Work that belongs to TRL 4 or later (building or testing hardware, test articles, test plans and reports, build-log entries, purchasing lists, PCB layouts) must not be started. The prototype build plan (BLD, section 18) is TRL 3 paper work and is required. Where it already exists it is kept, flagged in the check output, and not extended. Only Amish changes `PHASE.yaml`.

Every repo carries a `CLAUDE.md` with the working rules for AI sessions: the TRL cap, decision rights (nothing is recorded as decided unless Amish decided it), one step per session, and a mandatory `docs/REVIEW.md` before stopping.

## 11. Concept media

Every repo at TRL 2 or above explains its idea visually. Media are generated from a build123d massing model with `.kit/concept.py`, never drawn by hand, so they stay in step with the design.

| File | Required | Purpose |
| --- | --- | --- |
| `media/hero.png` | TRL 2+ | Shaded isometric render with a 1.75 m person for scale; the website card image |
| `media/concept-blueprint.png` and `.pdf` | TRL 2+ | Blueprint concept sheet: orthographic and isometric views, scale, key figures, title block |
| `media/model.glb` and `media/viewer.html` | TRL 2+ | Interactive 3D viewer (glTF plus model-viewer) for the website |
| `media/cutaway.png` | When the inside matters | Section view showing internal parts |
| `media/exploded.png` | Recommended | Exploded view with numbered callouts matching the BOM |
| `media/flow.png` | When energy or material moves | System, energy or material flow diagram with losses |

Session commands in `.claude/commands/` (`/populate`, `/advance-trl3`, `/rein-in`, `/refresh-media`) carry the standard prompts, so every Claude Code session starts from the same instructions.

At TRL 2 a massing model is enough: correct overall proportions and main components. All concept media carry "CONCEPT, NOT FOR FABRICATION". The check warns when required media are missing at TRL 2 and fails at TRL 3.

## 12. Product renders

Every repo at TRL 3 shows the product as it would look, not only as a massing model.

- `cad/src/product_model.py` is the appearance model. It defines `product_parts()` (named parts with a shape and a material), `TITLE` ("Name: what it is") and `RENDER_VIEWS`. It is for renders only: every main dimension comes from `cad/src/model.py`, never typed in again.
- Where the appearance model departs from `model.py` (a chamfer, a label, a fastener drawn for realism), record the deviation in `docs/REVIEW.md` as "Proposed, awaiting Amish".
- Scale comes from context, not from a floating figure: a hand or forearm for handheld objects, and the posed mannequin (`mannequin()` in `.kit/context_parts.py`: stand, walk, push, ride, sit, reach) for anything a person uses at body scale.
- Renders are made with `.kit/export_views.py` (one scene per view) and `.kit/photoreal.py` (Blender Cycles), then captioned with `.kit/photo_caption.py`. Files are `media/render-<view>.png`; `media/render-hero.png` is required.
- Every caption names the project, the repository and the viewing direction, and carries "CONCEPT, NOT FOR FABRICATION".
- Captions never sit on the render. `.kit/photo_caption.py` adds a header band (title, concept label, repository) above the render and a footer band (view note) below it, wraps every line to the image width, and steps the font down to a floor before adding a line.
- The README opens with `media/render-hero.png`.
- Software-only and scene repositories (no single product) may use a scene render as the hero instead of a product model.

## 13. Storefront images

Two images, both made from `media/render-hero.png` by `python .kit/cards.py .`:

| File | Size | Purpose |
| --- | --- | --- |
| `media/card.png` | 800 x 800 | Square thumbnail for the organization profile page |
| `media/social-preview.png` | 1280 x 640, under 1 MB | GitHub social preview, shown when a repository link is shared |

- The social preview shows the area, name, one-line description, the first sentence of the pitch, the brand line and the repository address. Design Molecule repos read "Design Molecule · open hardware concept, TRL n"; OpenRatio repos read "OpenRatio · research and educational prototype, TRL n".
- GitHub has no API for the social preview. Upload it under the repository's Settings, Social preview, on release day.
- Regenerate both images whenever `render-hero.png` changes.
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

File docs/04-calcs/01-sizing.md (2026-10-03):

---
doc_id: CCB-CAL-001
title: CharCube sizing and first-principles checks
project: CharCube
doc_type: Calculation note
version: "0.6"
status: Draft
date: '2026-10-02'
author: Amish Chadha
license: CERN-OHL-S-2.0
revisions:
- version: "0.1"
  date: '2026-09-25'
  author: Amish Chadha
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

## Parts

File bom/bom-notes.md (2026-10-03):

# BOM notes

Prices are indicative USD estimates for TRL 3, priced by supplier type (drum reconditioner or scrap dealer, local fabricator, steel stockist, hardware shop, refractory supplier, electronics distributor). Named suppliers depend on the first region, which is still open (CCB-DDR-001 item 9). Item numbers match the exploded view (`media/exploded.png`), the components table in `docs/02-concept.md` and the drawing CCB-DWG-001. Item 14 is in the BOM but not modelled.

Value-engineering target: USD 320. Estimated cost of the constructable design: USD 546 (USD 226 over the target). The 18 lines are all priced, each with its basis in its notes (checked by `docs/04-calcs/sizing.py`, CCB-CAL-001 v0.6 section 11). Lines 15 to 17 ($22) were added when Amish accepted the recommendations for R6 and R8 on 2026-09-25 (CCB-DDR-002 items 12 and 13). The lifting aid (line 18, $160) is most of the overrun; it could serve several kilns on one site.

## Safety kit (required, outside the kiln parts target)

Decided by Amish, 2026-09-25 (CCB-DDR-001 item 2): the kiln parts value-engineering target ($320) covers kiln parts only, and the safety kit is required and listed separately. Decided by Amish, 2026-09-25 (CCB-DDR-002 item 16): this table and CCB-REQ-001 R10 are where the safety kit requirement is stated, since build notes are TRL 4 material.

| Item | Indicative cost (USD) |
| --- | --- |
| Fire extinguisher (or a 50 L water drum and a shovel) | 20 |
| Heat-resistant gloves | 10 |
| Eye protection | 5 |
| Dust mask for crushing char and cutting the blanket | 5 |
| **Total** | **40** |

## Changes at TRL 3

- Line 5: a 230 mm air shroud around the throat replaces the 25 mm pipe ring, which could not pass the secondary air (CCB-CAL-001 section 6; decided by Amish, 2026-09-25, CCB-DDR-002 item 11). $12 to $14.
- Line 6: two rings of 12 mm air holes in place of one ring of 10 mm holes; 30 holes (15 per ring) since DDR-002, to offset the baffle insert pressure drop.
- Line 7: the flue is 700 mm, since the jacket now carries its own 168 mm flue sleeve. $30 to $22.
- Line 8: the jacket has 2 mm walls and an integral sleeve. $55 to $60.
- Line 13: class 1 (special limits) thermocouple probes, needed for R9.

## Changes from DDR-002 (decided by Amish, 2026-09-25)

- Line 15: spiral baffle insert in the jacket sleeve, $7 (item 12).
- Line 16: 25 mm mineral wool blanket on the jacket shell, $8 (item 12). Mineral wool suits the jacket because its outer face stays below 100 °C.
- Line 17: 25 mm ceramic fibre blanket on the lid and top band, $6 (item 13), cut from the same product as line 11.

## Changes for construction (CCB-DDR-003, 2026-09-30, Draft)

Made under Amish's 2026-09-30 instruction to make the design physically buildable; accepted by Amish on 2026-10-02. The added parts were priced on 2026-10-02 (below).

- Line 1: sliding port dampers now held in riveted guide strips; 10 mm core probe hole.
- Line 2: 150 mm lid hole; collar rolled to the throat and riveted on by six tabs.
- Line 3: probe slot in the retort side; two M8 U-bolt handles on the lid.
- Line 4: bricks laid round the retort's edge, clear of the gas holes.
- Line 5: shroud riveted to the throat by six tabs; 60 mm band damper with a wing screw.
- Line 6: probe hole; riveted to the collar.
- Line 7: flue 650 mm (was 700 mm), resting on three riveted stop clips; rain cap on three riveted legs.
- Line 8: three 6 mm fins welded to the jacket for the legs; loose lid located by tabs; vent nipple with locknuts.
- Line 10: legs bolted to the jacket fins and pinned to bolted foot cleats and pads; the flat-bar ring seat is gone.
- Line 12: blocks laid as a pinwheel.
- Line 13: core probe 500 mm, in through the drum side; throat probe 300 mm.
- Line 14: fasteners listed (rivets, M10 and M8 bolts, U-bolts, wing screw, hose clips).
- Line 15: strip about 615 mm, hung on a 10 mm rod through the flue foot.

## Priced on 2026-10-02 (approved follow-ups)

- Parts added for construction, $17 in all: line 1 guide strips +$2, line 3 U-bolts +$3, line 7 clips and cap legs +$2 (the conical cap from 1.5 mm sheet costs about the same as the flat 3 mm plate it replaces), line 8 fins, flare and lift-bar holes +$5, line 10 foot cleats and pads +$5, line 14 extra fasteners +$3 (with the labels below), line 15 hanger rod +$1 (the baffle line is now $8).
- Decided on 2026-10-02, $186 in all: line 12 ceramic fibre board +$28; line 13 block thermocouple and third amplifier +$10; line 14 two ISO 7010 W017 labels +$8; line 18 lifting aid $160.
- Line 8: the bottom 20 mm of the sleeve is flared to about 190 mm, and two 18 mm holes across the top socket take the lift bar.

The largest cost drivers are the lifting aid ($160), the water jacket ($65), the temperature logger ($42), the plinth with its fibre board ($40), the insulation blanket ($35) and the retort drum ($28). Drums are priced as used. Never use a drum that held fuel, solvent or pesticide, and never use galvanized pipe or drums in the hot path.

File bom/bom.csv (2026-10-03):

item | qty | spec | supplier | unit_cost_usd | make_buy | notes
1 Outer drum (firebox shell) | 1 | 200 L (55 US gal) open-head steel drum, 572 mm diameter x 851 mm, 1.2 mm body, with lid and locking ring; four 40 x 110 mm primary air ports cut 20 mm above the floor, each with a curved 60 x 122 mm sliding damper held in two riveted guide strips; one 10 mm hole at the back, 361 mm above the floor, for the core probe | Drum reconditioner or scrap dealer (used drum) | 22.00 | make | Indicative price: used drum about $20 plus about $2 for 1.1 m of 10 x 1.5 mm guide strip and 16 rivets (priced 2026-10-02); used drum that held a non-flammable non-toxic product only; burn off paint outdoors before use
2 Outer lid with flue collar | 1 | Drum lid from item 1 with a 150 mm centre hole; a 160 mm bore collar rolled from 1.5 mm sheet, 40 mm high, riveted to the lid by six folded tabs; ceramic gasket rope seal | Local fabricator | 10.00 | make | Indicative price for collar and gasket; no welding; the throat stands on the lid inside the collar (CCB-DDR-003)
3 Inner retort | 1 | 114 L (30 US gal) open-head steel drum with bolt-ring lid, 463 mm diameter x 737 mm, 1.0 mm body; eight 20 mm gas holes in the base on a 300 mm circle; a 10 x 40 mm slot in the side for the core probe; two M8 U-bolt handles through the lid | Drum reconditioner or scrap dealer (used drum) | 28.00 | make | Indicative price: used drum about $25 plus two M8 U-bolts with nuts and washers about $3 (priced 2026-10-02); consumable part (estimate 50 to 100 batches)
4 Firebrick standoffs | 3 | Half firebricks, about 114 x 64 x 60 mm, laid long side round the retort, centred 200 mm from the axis, clear of the gas holes | Building or refractory supplier | 2.00 | buy | Indicative price
5 Secondary air shroud and damper | 1 | 1.5 mm steel sleeve 230 mm diameter x 150 mm with a closed top ring, riveted to the throat by six folded tabs; open bottom 40 mm above the lid; 60 mm sliding band damper with a wing screw | Local fabricator | 14.00 | make | Indicative price; replaces the 25 mm pipe ring of TRL 2 (inlet too small; see CCB-CAL-001 section 8); riveted and folded, no welding
6 Burner throat (afterburner) | 1 | 160 mm x 2 mm plain steel pipe, 400 mm long, two staggered rings of 15 x 12 mm air holes inside the shroud (30 holes), one 8 mm hole for the throat probe; stands on the lid inside the collar, four rivets | Steel stockist | 15.00 | make | Indicative price; drilled only; 30 holes in place of 24 to offset the baffle insert pressure drop (CCB-CAL-001 v0.2 section 6)
7 Flue pipe with rain cap | 1 | 160 mm x 2 mm plain (not galvanized) steel pipe, 650 mm long, its foot 50 mm inside the jacket sleeve; three 20 x 20 x 3 mm angle stop clips riveted on rest it on the sleeve rim; two 11 mm holes for the baffle rod; conical rain cap 260 mm across, 30 degree slope, rolled from a 300 mm disc of 1.5 mm sheet with a 48 degree wedge cut out, riveted to three 20 x 3 mm flat-bar legs riveted to the flue top; shortest gap from the flue lip to the cap 60 mm | Steel stockist | 24.00 | buy | Indicative price: pipe about $18, cap sheet about $3, clips, legs and rivets about $3 (priced 2026-10-02); outlet about 2.72 m above ground; conical cap decided by Amish 2026-10-02 and now in the model and drawings
8 Water jacket | 1 | Annular steel tank, 420 mm outside diameter x 600 mm, 2 mm walls, welded water-tight around an integral 168 x 2 mm flue sleeve 700 mm long (50 mm sockets each end), its bottom 20 mm flared to about 190 mm, and two 18 mm holes across the top socket for the lift bar; three 6 mm steel fins welded to the shell for the tripod legs; about 61 L at 540 mm depth; open top with a loose 1.5 mm lid (210 mm centre hole, three locating tabs) and a 3/4 in steel vent nipple held by two locknuts | Local fabricator | 65.00 | make | Indicative price: fabricator quote basis about $60 for the tank plus about $5 for the three fins, the flare and the lift-bar holes (priced 2026-10-02); the only welded part (shell, sleeve, bottom ring, fins and tap socket); the sleeve weld carries the whole unit when it is lifted; must never be sealed
9 Draw-off tap | 1 | 1/2 in brass ball valve, nipple and socket welded to the jacket base | Hardware shop | 12.00 | buy | Indicative price
10 Jacket support tripod | 1 | Three legs of 40 x 40 x 4 mm steel angle about 1.55 m long, each bolted flat to a jacket fin with two M10 bolts and pinned with one M10 bolt to a 60 mm cleat of the same angle, bolted to a 100 x 100 x 6 mm foot pad; feet at 720 mm radius | Local fabricator | 25.00 | make | Indicative price: about $20 of angle for the legs plus about $5 for 0.2 m of angle for the cleats and three 100 x 100 x 6 mm pads (priced 2026-10-02); bolted (CCB-DDR-003: the ring seat is replaced by fins on the jacket)
11 Insulation blanket | 1 | 25 mm ceramic fibre blanket 128 kg/m3, about 1.9 x 0.7 m, held by plain steel wire mesh; air ports left clear | Refractory or kiln supplier | 35.00 | buy | Indicative price; wear a dust mask when cutting
12 Plinth | 1 | Four 390 x 190 x 190 mm concrete blocks laid as a pinwheel 580 mm square; a 600 x 600 x 25 mm ceramic fibre board (1260 °C grade, cut from a 600 x 900 mm sheet) on the blocks, with a 4 x 4 mm groove in its underside for the block thermocouple; a 760 x 600 x 3 mm steel ash pan on the board | Building supplier and scrap dealer | 40.00 | buy | Indicative price: blocks and pan about $12; fibre board sheet about $28 (refractory supplier list prices for 25 mm 1260 °C board, 600 x 900 mm, priced 2026-10-02); board decided by Amish 2026-10-02 (CCB-DDR-003 A2), dropped on later builds only if a measured burn without it keeps the blocks under about 150 °C; wear a dust mask when cutting
13 Thermocouple logger | 1 | Three type K probes: two class 1 (special limits), 6 mm stainless sheath, 500 mm (retort core, in through the drum side) and 300 mm (throat exit); one bare-wire glass-fibre insulated type K with a 1 m lead, its tip on the back plinth block under the fibre board; three MAX31855 amplifiers; small microcontroller with microSD; weatherproof box strapped to a tripod leg; USB power bank 10,000 mAh | Electronics distributor | 42.00 | buy | Indicative price: logger and two probes about $32; block thermocouple about $6 and a third amplifier board about $4 (priced 2026-10-02); firmware not started (beyond TRL 3)
14 Hardware and consumables | 1 | Rivets (4.8 mm steel), M10 bolts with nyloc nuts (9), M8 countersunk screws and nyloc nuts (6), M6 wing screw, washers, ceramic gasket rope, high-temperature sealant, tie wire, two stainless hose clips for the logger; two ISO 7010 W017 hot-surface warning labels, 100 mm aluminium triangles, wired to the drum blanket and the jacket blanket mesh at the front right | Hardware shop | 26.00 | buy | Indicative price: fasteners and consumables about $18 (about $3 more than first priced, for the fasteners added for construction); two aluminium labels about $8 (priced 2026-10-02); labels decided by Amish 2026-10-02
15 Spiral baffle insert | 1 | 1.5 mm plain steel strip 150 mm wide x about 615 mm, twisted half a turn per 300 mm, with an 11 mm hole near the top; hangs on a 10 mm steel rod 160 mm long through two holes in the flue foot | Local fabricator | 8.00 | make | Indicative price: strip about $7 plus the 10 mm hanger rod about $1 (priced 2026-10-02); decided by Amish 2026-09-25 (DDR-002 item 12); lifts out with the flue for tar and soot cleaning
16 Jacket shell blanket | 1 | 25 mm mineral wool (rock wool) blanket, about 1.4 x 0.55 m, held by plain steel wire; tap, vent and loose lid left clear | Building or insulation supplier | 8.00 | buy | Indicative price; decided by Amish 2026-09-25 (DDR-002 item 12); water side stays below 100 °C
17 Lid and top band blanket | 1 | 25 mm ceramic fibre blanket 128 kg/m3, annular disc about 0.62 m outside and 0.28 m inside diameter plus a 32 mm skirt over the top band and locking ring, held by wire | Refractory or kiln supplier | 6.00 | buy | Indicative price; decided by Amish 2026-09-25 (DDR-002 item 13); kept clear of the air shroud intake; lifted off with the lid
18 Lifting aid for the heat-recovery unit | 1 | A swinging arm on a post with a hand winch: post of 88.9 x 3.2 mm steel tube about 4.7 m long (4.0 m above ground), turning in a 101.6 x 3.6 mm ground sleeve 730 mm long set in a 600 x 600 x 750 mm concrete footing 1.2 m behind the kiln; arm of two 50 x 50 x 5 mm angles 1.5 m long bolted either side of the post top (M16), braced by two 40 x 40 x 4 mm angles (M16 and M12); two 100 mm steel pulleys on M12 axles; hand brake winch rated 270 kg (600 lb) on the post; about 9 m of 5 mm steel wire rope; hook with safety latch; 16 mm lift bar 230 mm long through the jacket sleeve socket | Steel stockist, hardware shop and building supplier | 160.00 | make | Indicative price (priced 2026-10-02): tube and sleeve about $53, angles about $18, pulleys about $10, winch about $30, rope and clips about $10, hook, bar and shackle about $8, bolts and spacers about $6, cement, sand and gravel for the footing about $25; decided by Amish 2026-10-02 (heat-recovery unit lifting aid); bolted, no welding; lifts the drained unit 1.55 m and swings it clear; can serve several kilns on one site

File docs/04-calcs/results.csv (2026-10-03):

id | requirement | value | target | status
R1 | Batch of 10 kg or more air-dry residue (packed or bundled feed, decided) | 12.0 kg packed (loose straw 4.0 kg, excluded) | >= 10 kg | met
R2 | Biochar 25 % or more of dry feed | 28% (20% to 35%); 2.96 kg | >= 25 % | at risk
R3 | Core 450 °C or more for 30 min, logged | core at 450 °C 4.0 h after lighting (2.9 to 6.5 h) if the annulus is held at 650 °C | 450 °C, 30 min | at risk
R4 | Burn the gas; smoke limits; CH4 below 24 g/kg char | routing closed by design; draft margin 2.4; emissions not calculable | < 24 g/kg | not verifiable at TRL 3
R5 | Light to end of flaming 5 h or less (relaxed, DDR-002); unload within 16 h | burn 4.5 h (3.4 to 7.0 h); unload after about 8 h | <= 5 h; <= 16 h | at risk
R6 | 10 MJ or more into water per batch | 11.5 MJ with baffle insert and jacket blanket (9.0 to 19.1 MJ) | >= 10 MJ | at risk
R7 | Water circuit open to air, no sealing valve, tap at base, jacket on tripod | open vent and loose lid; tripod-carried | by design | met
R8 | 5 kg or less of dry wood per batch | 3.7 kg (1.7 to 9.8); light-up alone 1.7 kg | <= 5 kg | at risk
R9 | 2 x type K, ±5 °C to 700 °C and indicative to 1,000 °C (restated, DDR-002), 10 s, 24 h on a power bank | ±3.4 °C to 700 °C with class 1 probes; 6 of 31 Wh | ±5 °C to 700 °C | met
R10 | Parts $320 or less (value-engineering target); safety kit listed separately (decided) | $546, every part priced (lifting aid $160); $226 over the target | <= $320 | not met
R11 | Hand tools, one welded part, no lift above 25 kg per person | unit 47.2 kg raised by the winch of the bolted lifting aid (post moment factor 4.3); heaviest hand lift: retort with char 15.5 kg | <= 25 kg | met
R12 | Outlet 2.5 m or more; 5 m clearance; no galvanized hot parts | outlet 2.72 m; 0 galvanized lines | >= 2.5 m | met

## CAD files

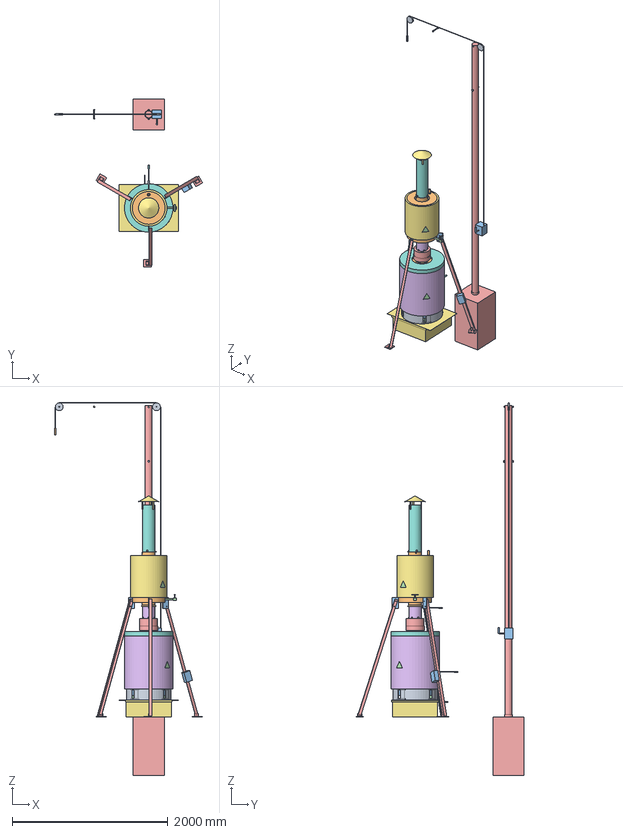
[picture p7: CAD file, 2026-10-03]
cad/step/charcube-assembly.step
1902.0 x 2160.4 x 4785.5 mm

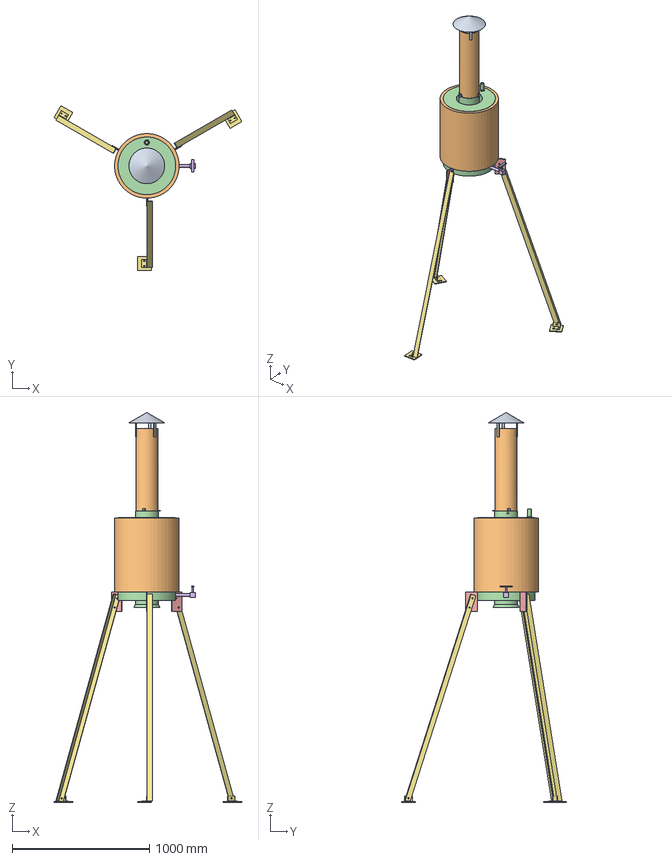
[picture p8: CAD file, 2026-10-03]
cad/step/charcube-heat-recovery-unit.step
1367.1 x 1198.6 x 2837.7 mm

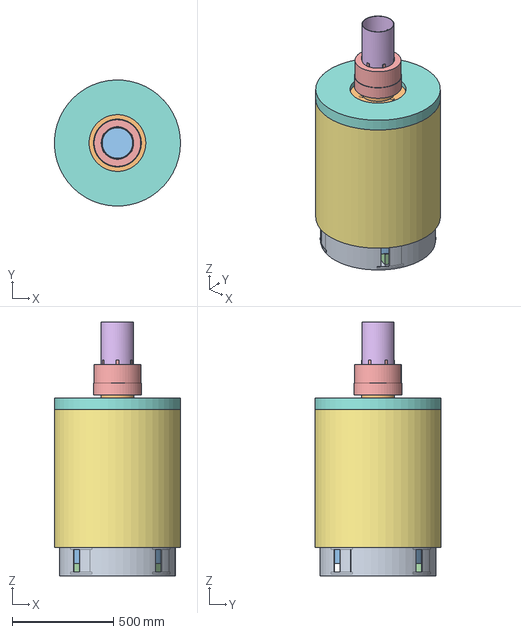
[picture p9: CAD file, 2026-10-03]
cad/step/charcube-kiln.step
621.4 x 621.9 x 1252.5 mm

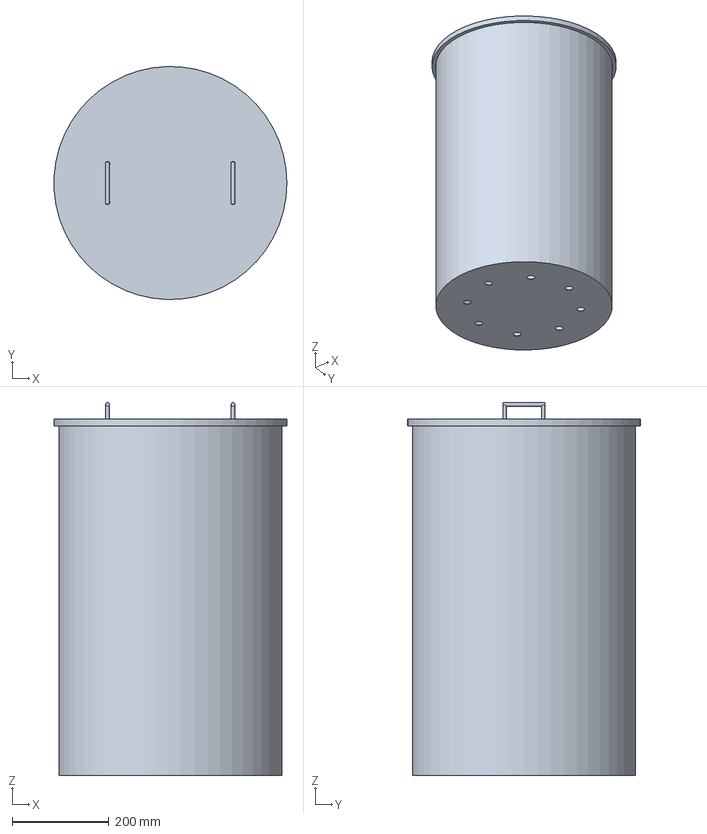
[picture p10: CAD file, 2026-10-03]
cad/step/charcube-retort.step
482.5 x 482.8 x 773.0 mm

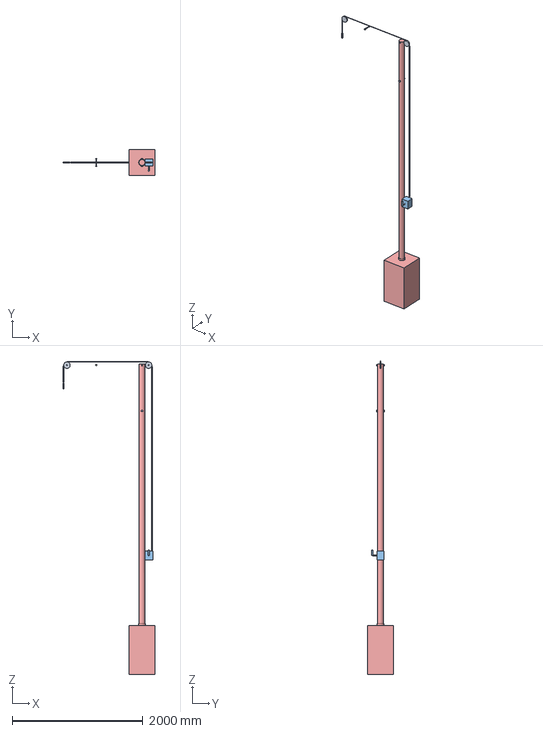
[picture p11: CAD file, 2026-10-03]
cad/step/charcube-lifting-aid.step
1410.0 x 400.0 x 4785.5 mm

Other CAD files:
cad/stl/charcube-assembly.stl
cad/stl/charcube-heat-recovery-unit.stl
cad/stl/charcube-kiln.stl
cad/stl/charcube-lifting-aid.stl
cad/stl/charcube-retort.stl

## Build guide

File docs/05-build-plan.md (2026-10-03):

---
doc_id: CCB-BLD-001
title: CharCube prototype build plan
project: CharCube
doc_type: Build plan
version: "0.2"
status: Draft
date: '2026-10-02'
author: Amish Chadha
license: CERN-OHL-S-2.0
revisions:
  - version: "0.1"
    date: '2026-09-30'
    author: Amish Chadha
    change: First build plan, with pictures by component and step; design made constructable (CCB-DDR-003)
  - version: "0.2"
    date: '2026-10-02'
    author: Amish Chadha
    change: Amish's 2026-10-02 decisions built in (fibre board and block thermocouple, flared sleeve foot, conical rain cap, hot-surface labels, lifting aid); pictures regenerated
---

# CharCube prototype build plan

**Plan, not yet built.** How to build the first proof-of-concept prototype, component by component. Building and testing to it is TRL 4 work. Decisions still to be made are kept in the design decisions register ([docs/06-design-decisions.md](06-design-decisions.md)), not here.

## 1. What you are building

Figure 1. Every component, pulled apart and numbered in build order

*Figure 1. Every component pulled apart and numbered in build order.*

The prototype is one CharCube kiln, about 2.84 m tall to its rain cap, with a lifting aid beside it: a 114 L steel drum (the retort) packed with residue, standing on bricks inside a 200 L drum on a block plinth shielded by a fibre board, with a burner throat and air shroud on the outer drum's lid, and a water jacket carried above it on a three-legged stand with the flue rising through it. A post with a swinging arm and a hand winch stands 1.2 m behind the kiln to lift the heat-recovery unit on and off. Figure 1 shows the 26 components in the order you make or fit them. Most are made in a small workshop from two used drums, plain steel pipe, sheet, strip and angle, by cutting, drilling, rolling sheet by hand, folding and riveting; the legs and feet are bolted. The water jacket is the one welded part and goes to a welder. The lifting aid is bolted together from steel tube and angle. The blocks, fibre board, bricks, blankets, tap, probes, logger, labels and winch are bought. The parts cost about $546 from the bill of materials, of which the lifting aid is about $160.

> **Safety:** CharCube is a fire that makes flammable, toxic gas and hot water. Build it so that it is only ever lit outdoors, at least 5 m from buildings, fences and dry vegetation, with a fire extinguisher or 50 L of water and a shovel at hand. Use only drums that held non-flammable, non-toxic products, and never cut, drill or grind a drum that held fuel, solvent or pesticide. Never use galvanized pipe or sheet anywhere in the hot path. Wear eye protection, gloves and hearing protection when cutting and grinding, and a dust mask when cutting ceramic fibre or mineral wool. The water jacket must stay open to the air: never fit a sealed lid, valve or plug.

## 2. What changed to make it buildable

The concept showed what the kiln does; some of its parts could not be made, fixed or used as drawn. Each change below keeps what the kiln does, and all of them are recorded in decision record CCB-DDR-003, which Amish accepted on 2026-10-02 together with the fibre board, the flared sleeve foot, the conical rain cap, the labels and the lifting aid.

*Table 1. Changes from the concept.*

| Component | The concept had | The buildable design has | Why |
| --- | --- | --- | --- |
| Plinth | Four blocks that overlapped each other by 50 mm | Four blocks laid as a pinwheel, 580 mm square with a 200 mm hole (Figure 3) | The drum's rim stands on block all round |
| Lid and throat | A 160 mm lid hole the same size as the throat, so the throat had nothing to stand on | A 150 mm hole; the throat stands on the lid inside a riveted collar and is riveted to it (Figure 12) | Lid, throat and shroud lift off as one unit |
| Air shroud | No fixing; a band damper that floated and could not close the intake | Six tabs riveted to the throat; a 60 mm band with a wing screw (Figure 12) | Riveted and folded, no welding |
| Port dampers | Listed but not drawn | A curved plate sliding in two riveted guide strips per port (Figure 6) | A damper must be held top and bottom |
| Firebricks | Standing under the gas holes | Long side round the retort, 200 mm out, 8 mm clear of the holes (Figure 8) | The gas holes vent freely |
| Retort | Nothing to lift it by in a 43 mm gap | Two U-bolt handles on its lid | Hands do not fit beside it |
| Jacket stand | A ring seat 7 mm below the jacket and outside its edge; round stand-in legs | Three fins welded to the jacket; angle legs bolted flat to them; bolted foot cleats and pads (Figures 18, 20) | Every joint is face to face and bolted |
| Flue and rain cap | No seat for the flue; cap posts inside the bore; cap 10 mm above the outlet | A 650 mm flue resting on three clips; a conical cap on three riveted legs, at least 60 mm from the flue's top edge (Figures 22, 24) | The flue sits on the jacket; the outlet is at 2.72 m |
| Baffle | A cross bar cut into the flue wall | A rod through two holes in the flue foot; the strip hangs on it (Figure 22) | It lifts out with the flue |
| Jacket lid | Floating above the rim; a vent standing on nothing | Rests on the rim on three tabs; vent nipple through it (Figure 16) | Open to the air, located, removable |
| Logger | Box drawn through a leg | Strapped beside the leg | A box cannot share space with a leg |
| Probes | A short core probe through two lids from under the shroud | A 500 mm probe through the drum side into a slot in the retort; the throat probe below the sleeve (Figure 26) | Both can be pushed in and pulled out from outside |

## 3. Making the components

Make and check each component before the assembly step that needs it. Sizes are in millimetres. "Front" is the side the operator works from; "back", "left" and "right" are as seen standing in front of the kiln, and the tap is on the right. Workshop tolerance is 1 mm unless a step says otherwise; drawings do not carry tolerances before TRL 4.

### 3.1 Plinth blocks, fibre board, block thermocouple and ash pan

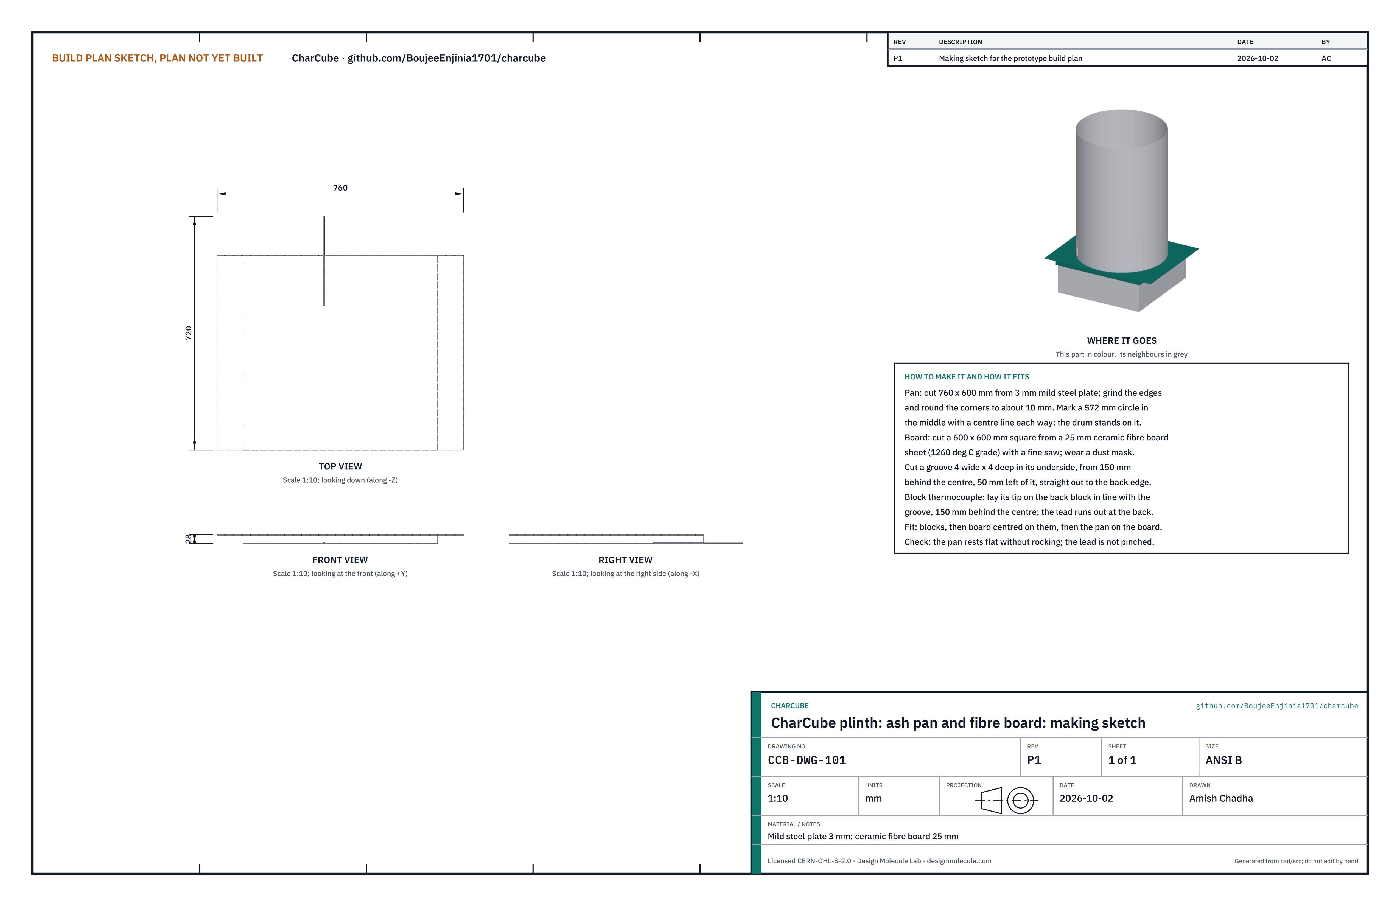
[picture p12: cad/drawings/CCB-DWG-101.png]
Figure 2. Making sketch of the ash pan and fibre board


*Figure 2. Plinth making sketch: ash pan, fibre board and block thermocouple (CCB-DWG-101).*

**What it is and what it is made from.** Four bought concrete blocks, 390 x 190 x 190; a 25 mm ceramic fibre board, 600 x 600, that keeps the heat of the fire off the blocks, since concrete can crack or spall when heated; a thermocouple with its tip on a block, to show how hot the blocks get; and a steel plate, 760 x 600 x 3, that lifts the drum's air ports clear of the ground and catches embers.

**How to make it.**

1. Cut the pan from 3 mm mild steel plate, 760 x 600. Grind the edges and round the corners to about 10.
2. Scribe a 572 circle in the middle and a centre line each way; the drum stands on the circle.
3. Cut the board, 600 x 600, from a sheet of 25 mm ceramic fibre board (1260 °C grade) with a fine saw, wearing a dust mask. On its underside cut a groove 4 wide and 4 deep, starting 150 behind the centre and 50 to the left of it and running straight out to the back edge.
4. The block thermocouple is bought: a bare-wire type K with glass-fibre insulation and a 1 m lead (section 3.20).

**How it fits the parts next to it.**

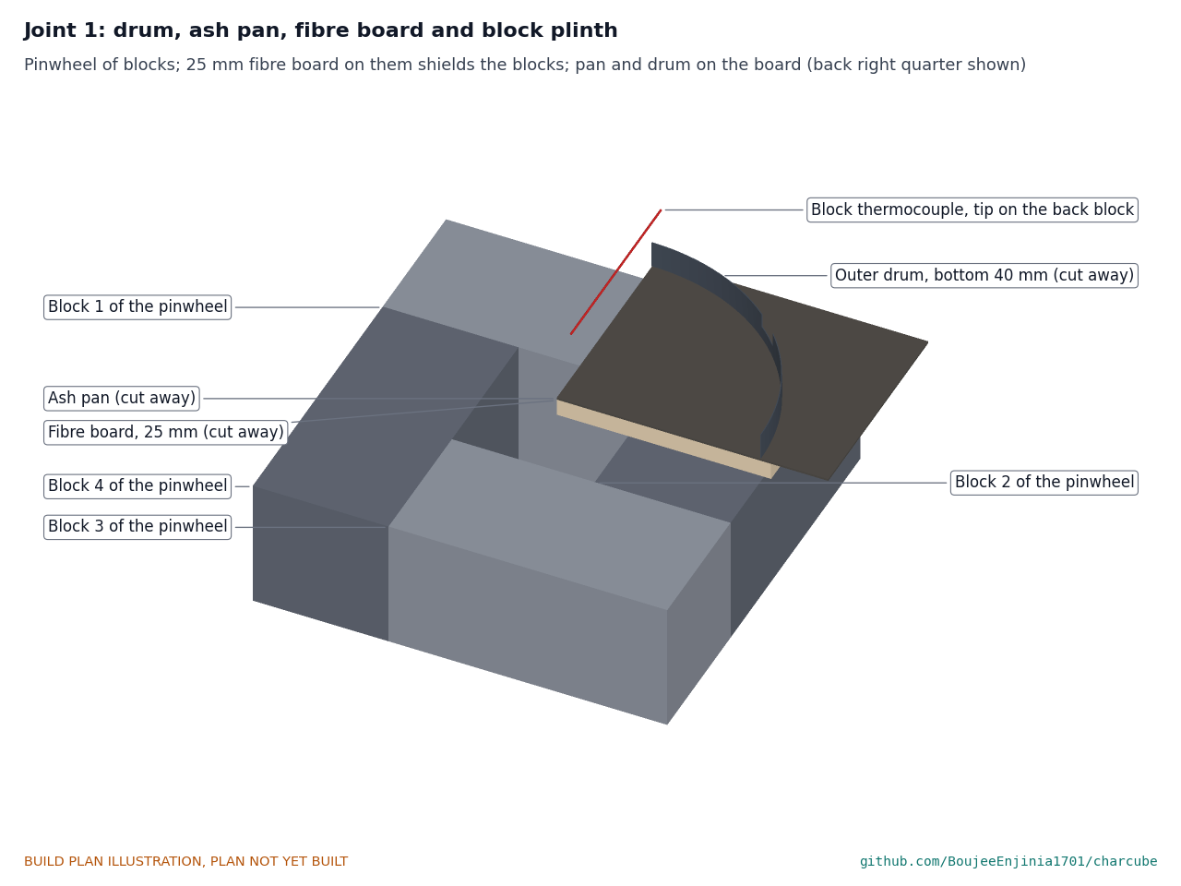
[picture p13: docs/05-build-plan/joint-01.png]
Figure 3. Joint 1: drum, ash pan and block plinth


*Figure 3. The four blocks make a 580 mm square round a 200 mm hole; the fibre board lies on them, the pan on the board, and the drum's rim stands over the blocks.*

Each block's end butts against the side of the next, turning the same way round the square. The thermocouple's tip lies on the back block, 150 behind the centre, and its lead runs out at the back along the groove, so the board does not pinch it. The board lies centred on the blocks and the pan lies flat on the board; the pan is 80 wider than the board at each side so embers from the ports land on steel.

**Check before moving on.** The pan lies level (a spirit level both ways) and does not rock; the thermocouple reads room temperature at the logger.

### 3.2 Outer drum

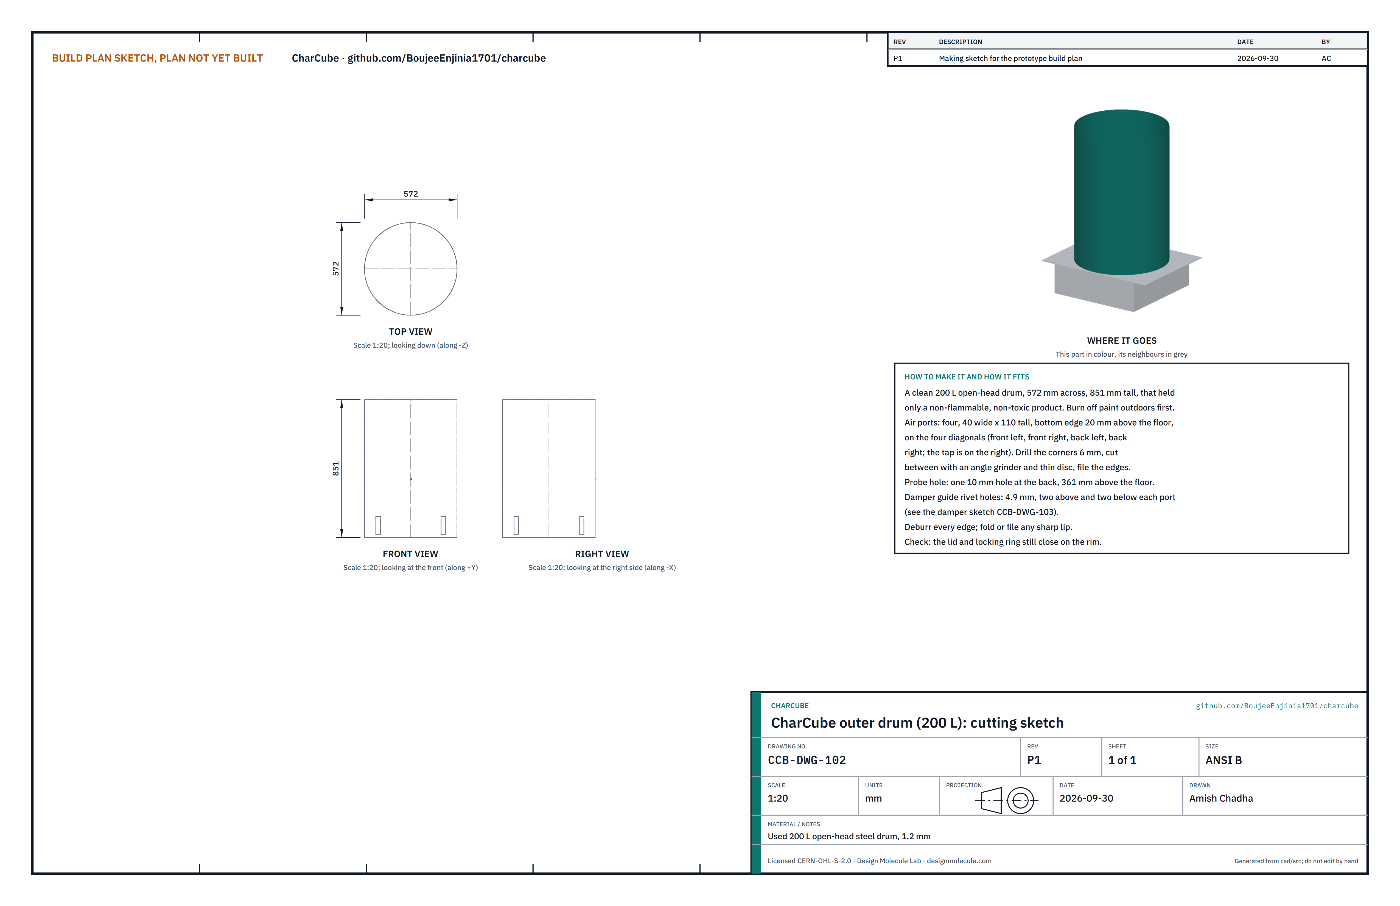
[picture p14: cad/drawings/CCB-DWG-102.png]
Figure 4. Cutting sketch of the outer drum


*Figure 4. Outer drum cutting sketch (CCB-DWG-102).*

**What it is and what it is made from.** A used 200 L open-head steel drum, 572 across and 851 tall, 1.2 thick, with its lid and locking ring: the firebox shell.

**How to make it.**

1. Check what the drum held. Burn off paint and liners outdoors, upwind, before any cutting (safety stop S1).
2. Mark four air ports, 40 wide and 110 tall, their bottom edges 20 above the floor, on the four diagonals (front left, front right, back left, back right).
3. Drill a 6 hole in each corner of each port and cut between the holes with an angle grinder and a thin disc. File the edges smooth.
4. Drill one 10 hole at the back, 361 above the floor, for the core probe.
5. Drill the damper guide rivet holes once the guides are made (section 3.3).
6. Deburr every edge.

**How it fits the parts next to it.** It stands on the pan over the blocks (Figure 3); the lid and its locking ring close on its rim; the blanket wraps it from 140 above the floor to 30 below the rim.

**Check before moving on.** The lid and locking ring still close on the rim.

### 3.3 Port dampers and guides (make 4 sets)

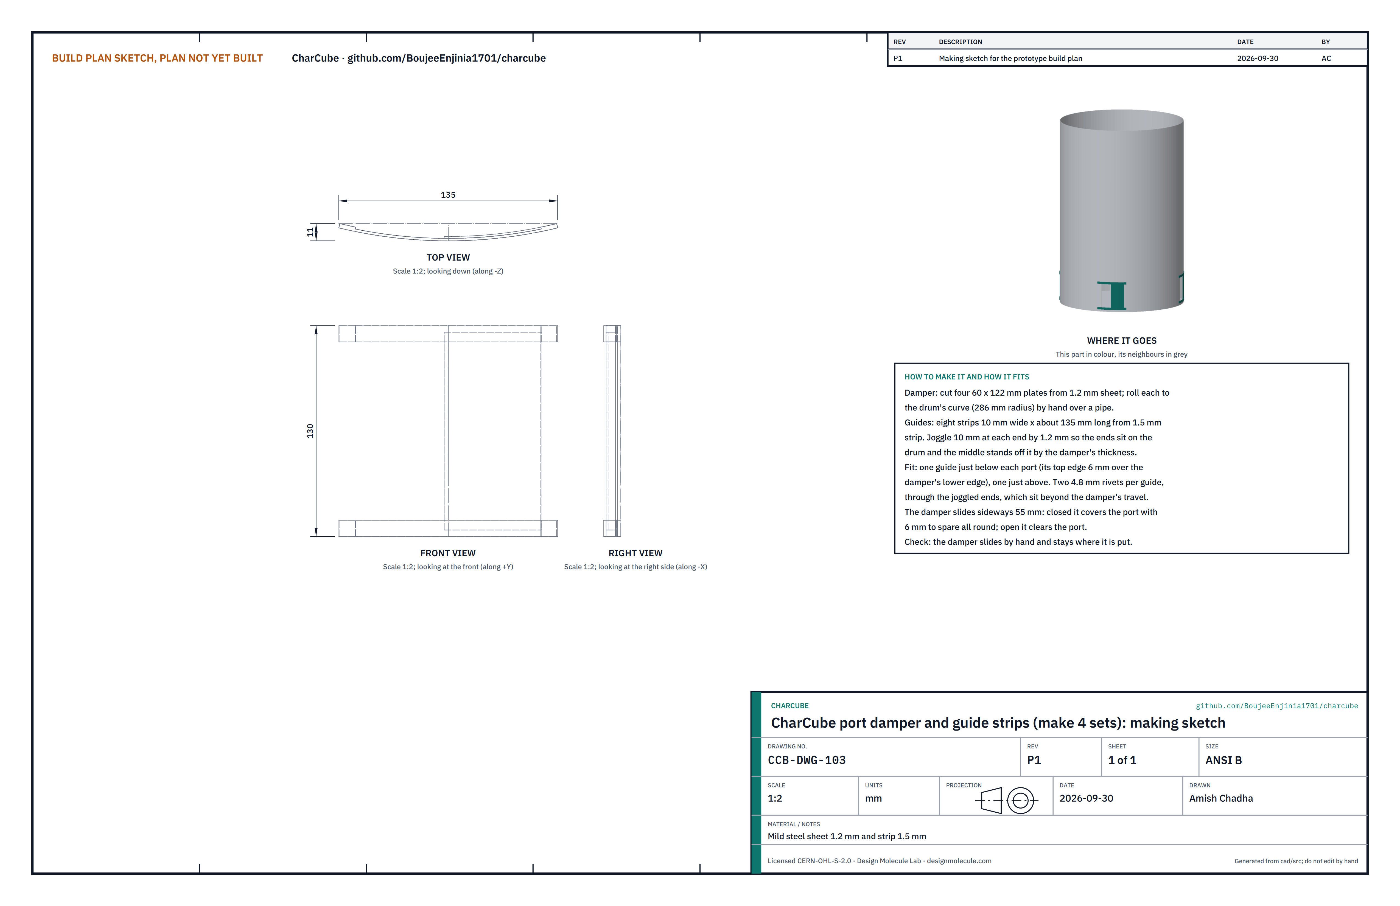
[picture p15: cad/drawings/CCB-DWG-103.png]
Figure 5. Making sketch of the port damper and guides


*Figure 5. Port damper and guide strips making sketch (CCB-DWG-103).*

**What it is and what it is made from.** At each port, a curved plate that slides sideways to open or close the port, held by two strips. Damper: 1.2 mm mild steel sheet. Guides: 1.5 mm steel strip, 10 wide.

**How to make it.**

1. Cut four dampers, 60 x 122. Roll each by hand over a pipe until it lies against the drum.
2. Cut eight guide strips about 135 long. Joggle 10 at each end by 1.2 so the ends sit on the drum and the middle stands off it by the damper's thickness.
3. Hold a damper over its port. Place one guide just below the port with its top edge 6 over the damper's lower edge, and one just above the port overlapping the damper's top edge by 6. The guides run from 10 short of the closed damper on one side to 10 past the open damper on the other.
4. Drill 4.9 through each joggled end and the drum and fit 4.8 steel rivets.

**How it fits the parts next to it.**

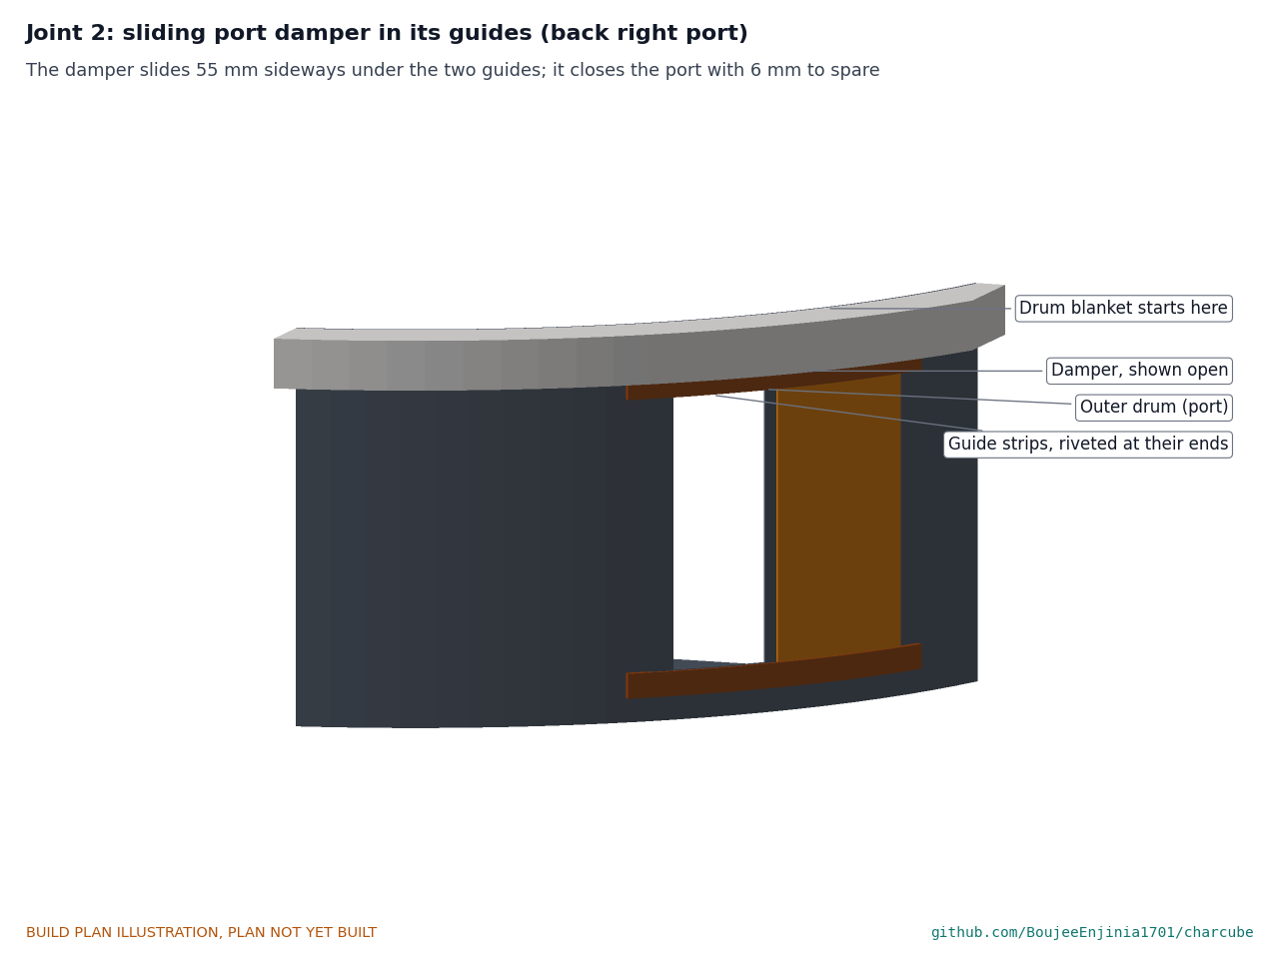
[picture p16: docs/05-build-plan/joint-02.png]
Figure 6. Joint 2: sliding port damper in its guides


*Figure 6. The damper slides 55 mm sideways under the two guides; closed, it covers the port with 6 mm to spare all round.*

**Check before moving on.** Each damper slides by hand from fully open to fully closed and stays where it is put.

### 3.4 Drum blanket

**What it is and what it is made from.** Bought 25 mm ceramic fibre blanket, 128 kg/m³, held by plain steel wire mesh: it halves the heat lost through the drum's side.

**How to make it.** Wearing a dust mask, cut a strip 681 wide and about 1.96 m long (once round the blanketed drum plus a 10 overlap). Cut a 20 slit where it crosses the probe hole.

**How it fits the parts next to it.** It wraps the drum from 140 above the floor (just above the port guides) to 30 below the rim; the lid blanket's skirt covers the top 30. Wire mesh over it, twisted tight, holds it.

**Check before moving on.** No blanket over any port or damper; the probe hole is clear.

### 3.5 Firebricks

**What it is and what it is made from.** Three bought half firebricks, about 114 x 64 x 60, that hold the retort 60 above the drum floor so fire can burn under it.

**How to make it.** Nothing to make. Lay them on the drum floor with their long side running round the drum, their centres 200 from the middle: one at the back and two toward the front, 120 degrees apart.

**How it fits the parts next to it.**

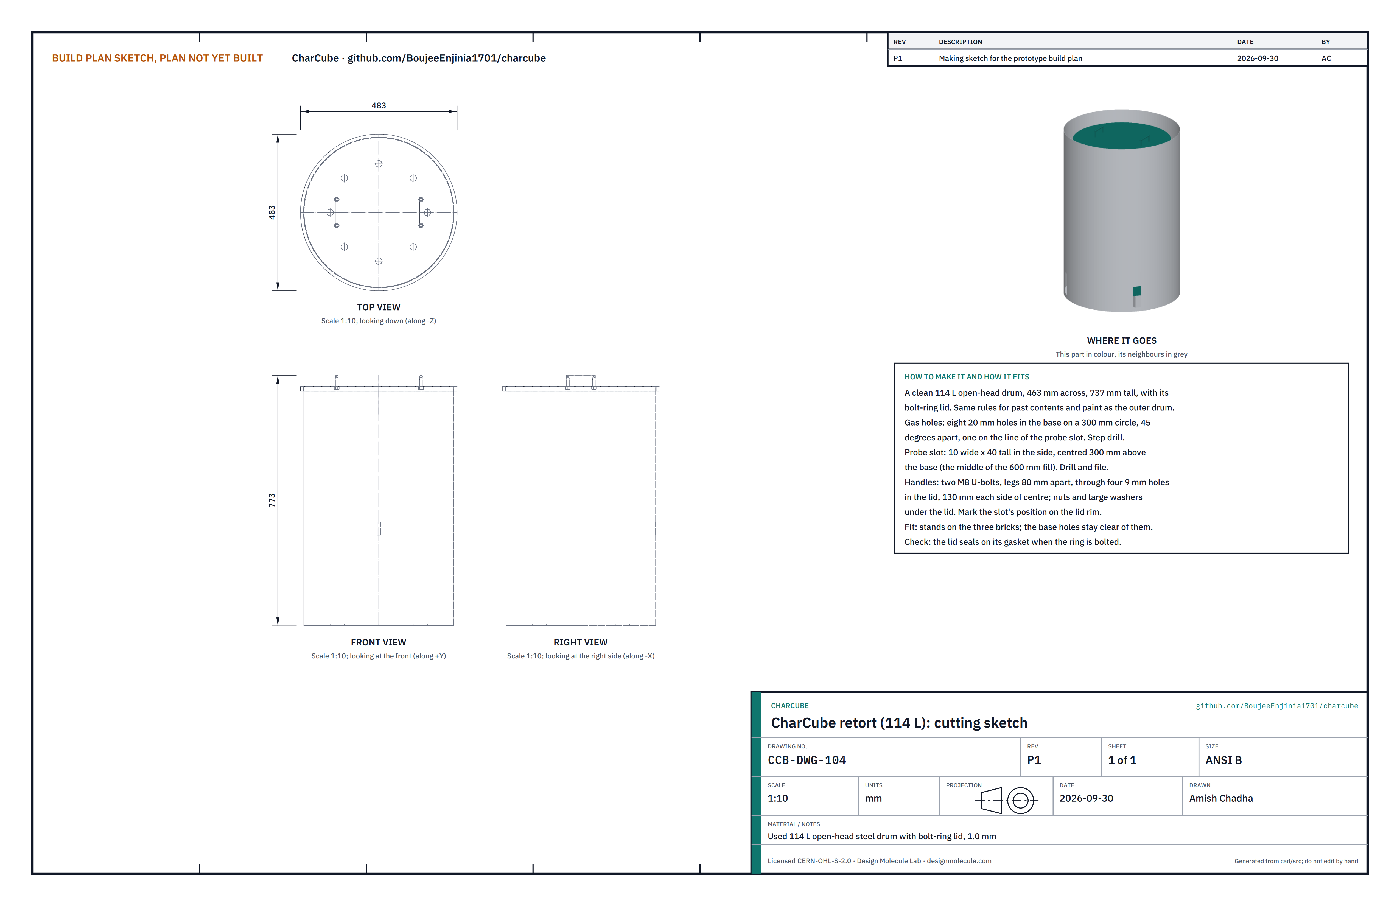
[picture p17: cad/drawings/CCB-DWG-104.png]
Figure 7. Making sketch of the retort


*Figure 7. Retort cutting sketch (CCB-DWG-104), shown here because the bricks are placed to suit its gas holes.*

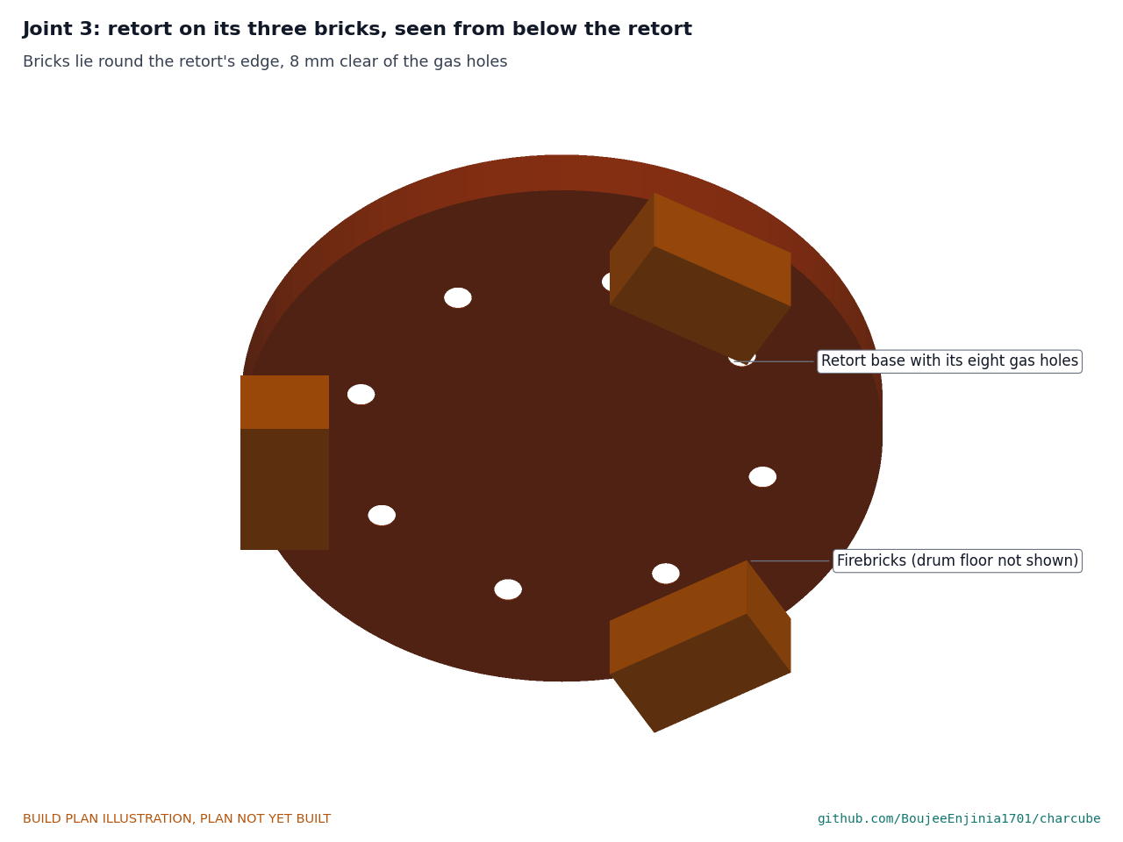
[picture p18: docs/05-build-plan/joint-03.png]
Figure 8. Joint 3: the retort on its bricks, seen from below


*Figure 8. The bricks carry the retort's edge and stay 8 mm clear of every gas hole.*

**Check before moving on.** With the retort in place, every gas hole can be seen from below, clear of the bricks.

### 3.6 Retort

**What it is and what it is made from.** A used 114 L open-head steel drum with its bolt-ring lid, 463 across and 737 tall, 1.0 thick (Figure 7). It holds the residue; it wears out in about 50 to 100 batches.

**How to make it.**

1. Same checks on past contents and paint as the outer drum (safety stop S1).
2. Mark eight gas holes in the base on a 300 circle, 45 degrees apart, one of them on the line of the probe slot. Step drill to 20.
3. Mark the probe slot, 10 wide and 40 tall, in the side, centred 300 above the base (the middle of the 600 fill). Drill and file it.
4. Drill four 9 holes in the lid, 130 each side of centre and 40 each side of the centre line, and fit two M8 U-bolts with large washers and nuts under the lid.
5. Mark the slot's position on the lid rim with a punch line, so it can be lined up with the drum's probe hole when the lid is on.

**How it fits the parts next to it.** It stands on the three bricks (Figure 8), 43 clear of the outer drum all round, with the U-bolts 17 below the outer lid.

**Check before moving on.** The lid seals on its gasket when the ring is bolted; the U-bolts carry the drum's weight without the lid bending.

### 3.7 Outer lid and throat collar

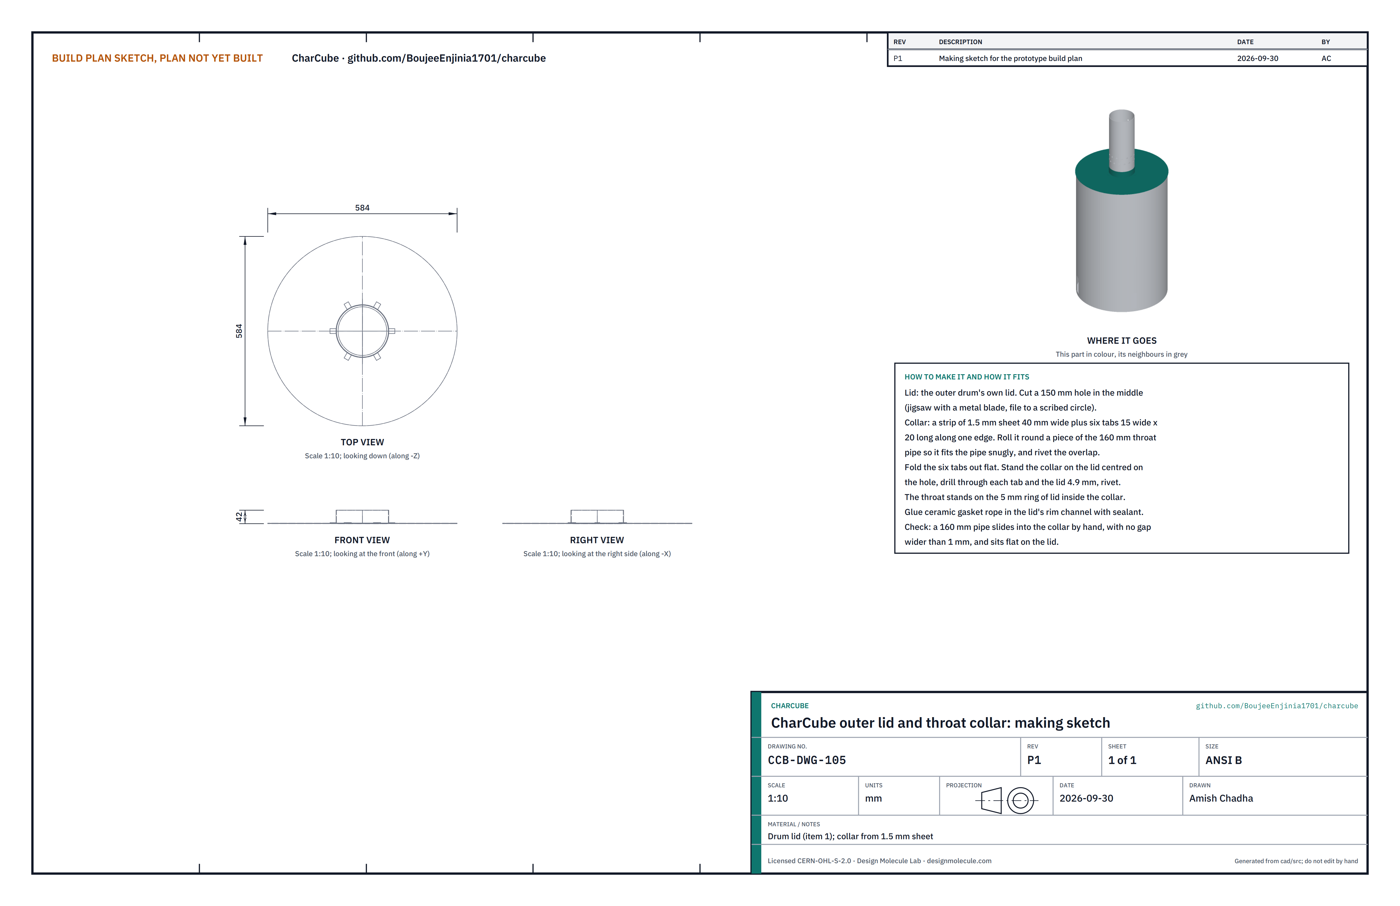
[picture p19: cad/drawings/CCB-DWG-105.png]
Figure 9. Making sketch of the outer lid and collar


*Figure 9. Outer lid and throat collar making sketch (CCB-DWG-105).*

**What it is and what it is made from.** The outer drum's own lid with a 150 hole, and a short collar of 1.5 mm sheet that holds the burner throat upright on it.

**How to make it.**

1. Cut a 150 hole in the middle of the lid with a jigsaw and a metal blade, and file it to a scribed circle.
2. Cut a strip of 1.5 sheet 40 wide and about 520 long, with six tabs 15 wide and 20 long along one edge.
3. Roll the strip round a piece of the 160 throat pipe so it fits the pipe snugly, and rivet the overlap.
4. Fold the tabs out flat, stand the collar on the lid centred on the hole, drill through each tab and the lid at 4.9, and rivet.
5. Glue ceramic gasket rope into the lid's rim channel with high-temperature sealant.

**How it fits the parts next to it.** The throat stands on the 5 ring of lid inside the collar and is riveted to it (Figure 12). The lid closes on the drum with its locking ring.

**Check before moving on.** A 160 pipe slides into the collar by hand, with no gap wider than 1, and sits flat on the lid.

### 3.8 Burner throat

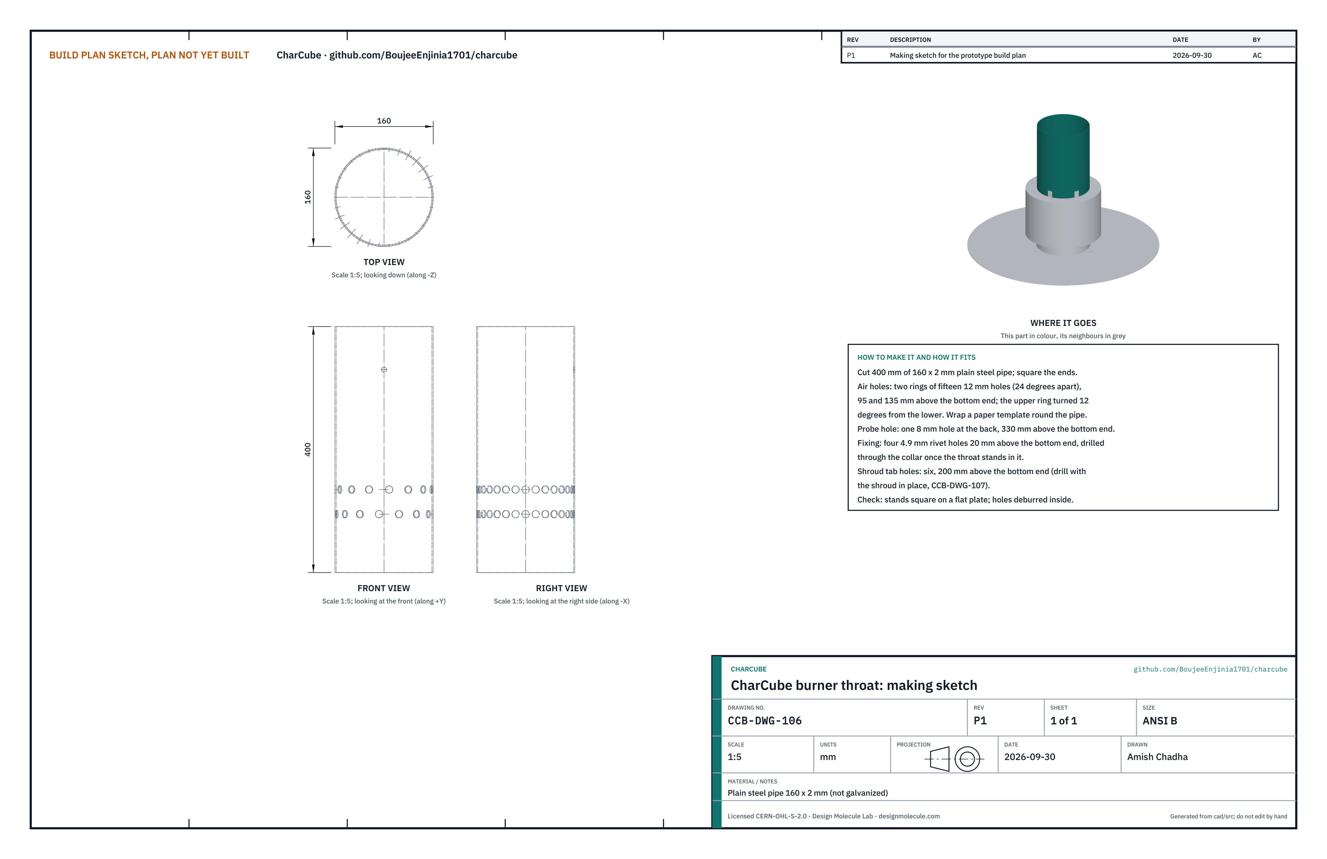
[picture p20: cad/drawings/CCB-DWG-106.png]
Figure 10. Making sketch of the burner throat


*Figure 10. Burner throat making sketch (CCB-DWG-106).*

**What it is and what it is made from.** A 400 length of 160 x 2 plain steel pipe, where the gas finishes burning with air from the shroud.

**How to make it.**

1. Cut 400 of pipe and square the ends.
2. Wrap a paper template round the pipe and mark two rings of fifteen 12 holes, 24 degrees apart, 95 and 135 above the bottom end, the upper ring turned 12 degrees from the lower. Drill and deburr inside.
3. Drill one 8 hole at the back, 330 above the bottom end, for the throat probe.
4. Stand it in the collar and drill four 4.9 holes through the collar and pipe, 20 above the lid; rivet.

**How it fits the parts next to it.** Collar and lid below (Figure 12); the shroud is riveted to it 200 above its bottom end; the jacket sleeve slips over its top 50 (Figure 14).

**Check before moving on.** It stands square to the lid; every air hole is clear.

### 3.9 Air shroud and band damper

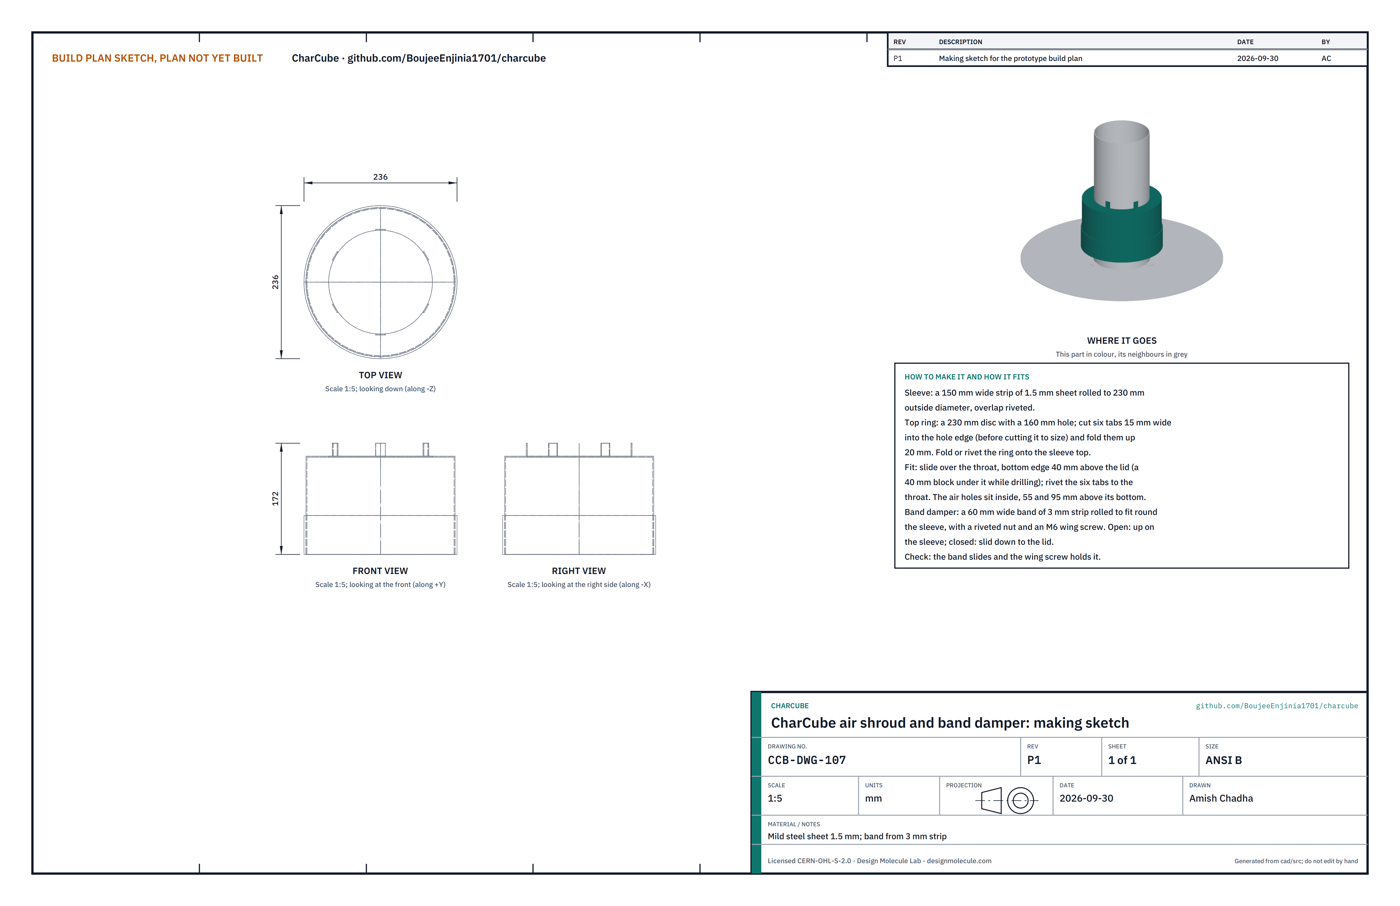
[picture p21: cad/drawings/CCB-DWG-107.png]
Figure 11. Making sketch of the air shroud and band damper


*Figure 11. Air shroud and band damper making sketch (CCB-DWG-107).*

**What it is and what it is made from.** A sleeve of 1.5 mm sheet round the base of the throat, open at the bottom, closed at the top, that feeds air to the throat's holes; and a band that slides down to close its intake.

**How to make it.**

1. Roll a strip 150 wide to 230 outside diameter and rivet the overlap.
2. Cut a 230 disc. Cut a 160 hole in it, first cutting six tabs 15 wide into the hole's edge, and fold the tabs up 20.
3. Fold or rivet the disc onto the top of the sleeve.
4. Band: roll 3 mm strip, 60 wide, to slide round the sleeve; rivet a nut into it and fit an M6 wing screw.

**How it fits the parts next to it.**

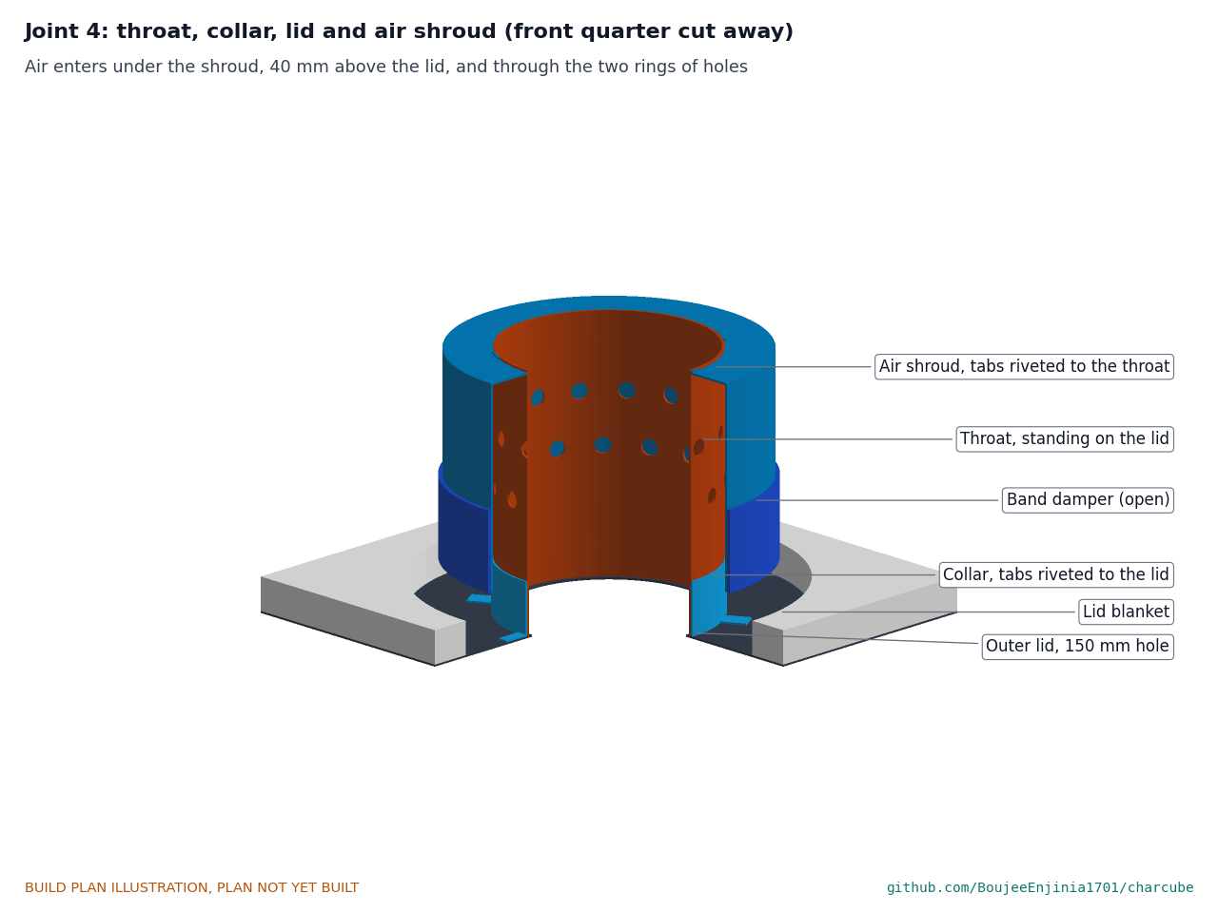
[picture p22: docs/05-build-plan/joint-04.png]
Figure 12. Joint 4: throat, collar, lid and air shroud


*Figure 12. The throat stands on the lid inside the collar; the shroud's tabs are riveted to the throat with its bottom edge 40 mm above the lid; air enters there and passes through the two rings of holes.*

Slide the shroud over the throat onto a 40 spacer block on the lid, drill through the six tabs and the throat at 4.9 and rivet. The band rides on the shroud: up and screwed tight for the burn, slid down to the lid to close the intake at the end.

**Check before moving on.** The gap under the shroud is 40 all round; the band slides and the wing screw holds it.

### 3.10 Lid blanket

**What it is and what it is made from.** Bought 25 mm ceramic fibre blanket: a disc on the lid and a skirt over the drum's top band and locking ring.

**How to make it.** Cut a ring 622 outside and 280 inside diameter, and a skirt 32 wide and about 1.96 m long. The 280 hole keeps the blanket 25 clear of the shroud so the intake is never blocked.

**How it fits the parts next to it.** It lies on the lid round the shroud (Figure 12); the skirt hangs over the rim and locking ring down to the side blanket. Tie wire holds both. It lifts off with the lid.

**Check before moving on.** The blanket is at least 25 from the shroud and band all round.

### 3.11 Water jacket

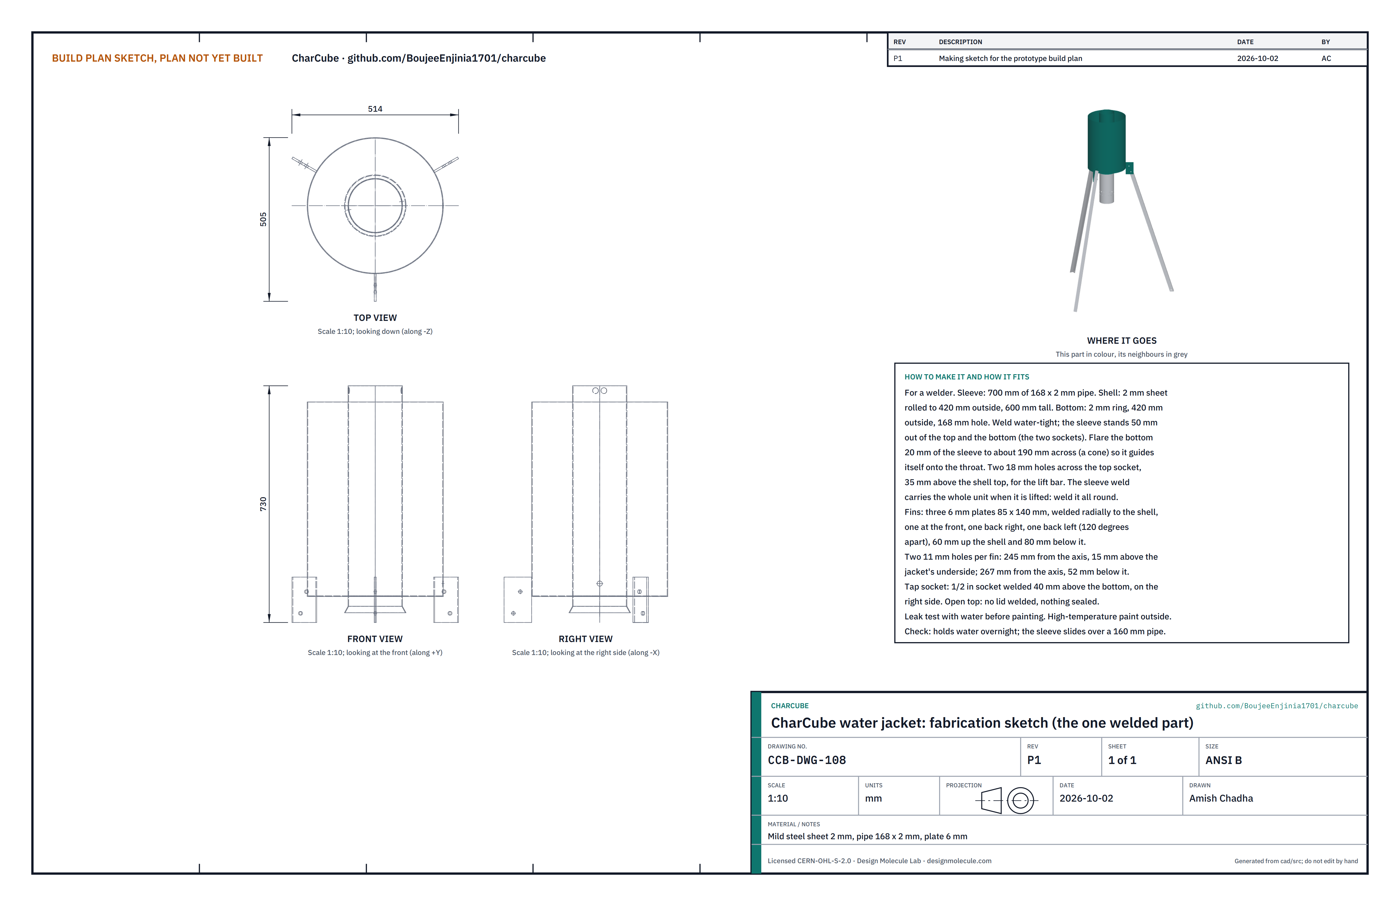
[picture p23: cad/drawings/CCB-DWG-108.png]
Figure 13. Fabrication sketch of the water jacket


*Figure 13. Water jacket fabrication sketch (CCB-DWG-108).*

**What it is and what it is made from.** An annular tank round a flue sleeve that heats about 61 L of water, made by a welder from 2 mm mild steel sheet, a 700 length of 168 x 2 pipe and 6 mm plate. It is the one welded part.

**How to make it (for the welder).**

1. Shell: 2 mm sheet rolled to 420 outside diameter, 600 tall. Bottom: a 2 mm ring, 420 outside with a 168 hole.
2. Weld the bottom to the shell and the sleeve through the bottom, water-tight, with the sleeve standing 50 out of the top and 50 out of the bottom. The top is open; nothing is welded over it. Weld the sleeve all round: when the unit is lifted, the sleeve carries all of it.
3. Flare the bottom 20 of the sleeve out to about 190 across, a short cone, so the sleeve guides itself onto the throat as the unit is lowered.
4. Drill two 18 holes straight across the top socket, 35 above the shell's top edge, for the lift bar (section 3.22). Turn them a quarter turn from where the flue's rod holes will sit.
5. Fins: three 6 mm plates, 85 wide and 140 tall, welded on edge to the shell, one at the front and one each at the back left and back right, 120 degrees apart. Each fin runs from 60 up the shell to 80 below the jacket's underside. Drill two 11 holes in each: 245 from the jacket's axis and 15 above its underside, and 267 from the axis and 52 below the underside.
6. Weld a 1/2 in socket into the shell on the right side, 40 above the bottom, for the tap.
7. Fill with water and leave overnight; fix any leak. Then paint the outside with high-temperature paint.

**How it fits the parts next to it.**

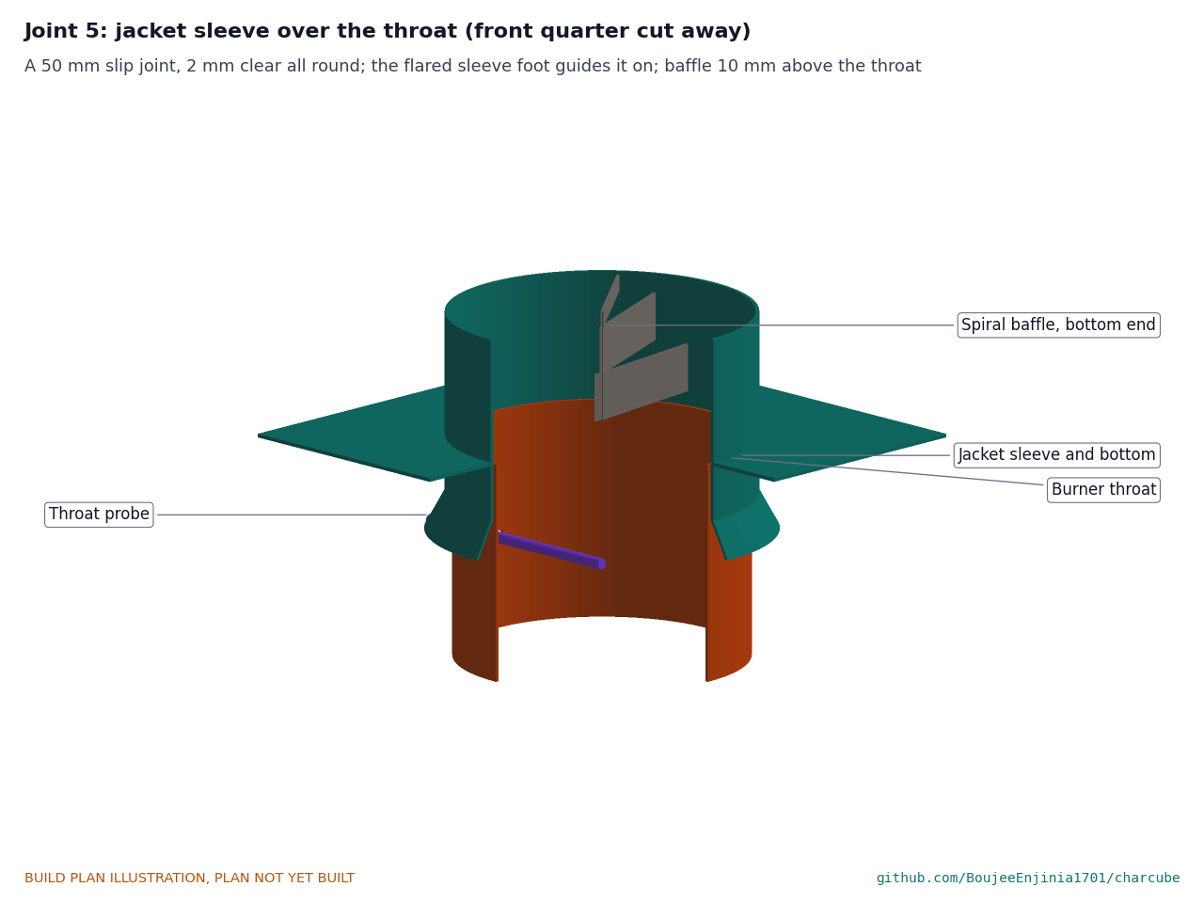
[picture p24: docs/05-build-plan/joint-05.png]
Figure 14. Joint 5: the jacket sleeve over the throat


*Figure 14. The lower 50 mm of the sleeve slips over the top of the throat with 2 mm clear all round; its flared foot guides it on; the baffle hangs 10 mm above the throat.*

The legs bolt to the fins (Figure 18); the flue rests on the sleeve's upper rim (Figure 22).

**Check before moving on.** It holds water overnight with no drip; the sleeve slides over a short piece of 160 pipe.

### 3.12 Tap

**What it is and what it is made from.** A bought 1/2 in brass ball valve with a short steel nipple.

**How to make it.** Nothing to make. Wrap the nipple's threads with PTFE tape.

**How it fits the parts next to it.** It screws into the jacket's socket on the right side, lever up. It must never be the only way the jacket breathes: the top stays open.

**Check before moving on.** No drip at the socket with the jacket full.

### 3.13 Jacket loose lid and vent

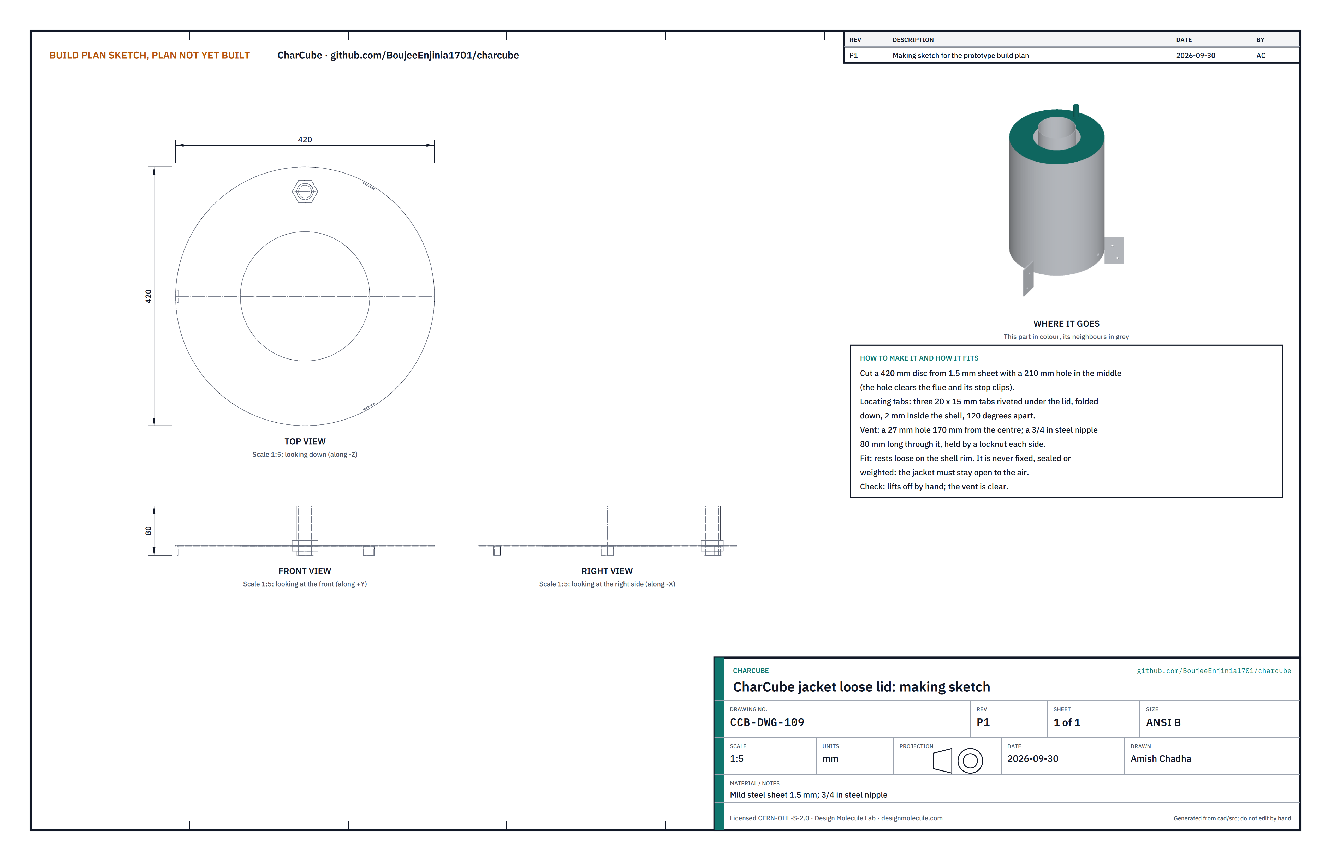
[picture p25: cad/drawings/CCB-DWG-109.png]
Figure 15. Making sketch of the jacket loose lid


*Figure 15. Jacket loose lid making sketch (CCB-DWG-109).*

**What it is and what it is made from.** A 420 disc of 1.5 mm sheet with a 210 centre hole that keeps rain and leaves out of the jacket; a 3/4 in steel nipple, 80 long, as a vent.

**How to make it.**

1. Cut the disc and the centre hole.
2. Rivet three tabs, 20 x 15, under the lid, 120 degrees apart, folded down so they sit 2 inside the shell.
3. Cut a 27 hole 170 from the centre and fit the nipple with a locknut each side.

**How it fits the parts next to it.** The centre hole clears the flue's stop clips (section 3.17).

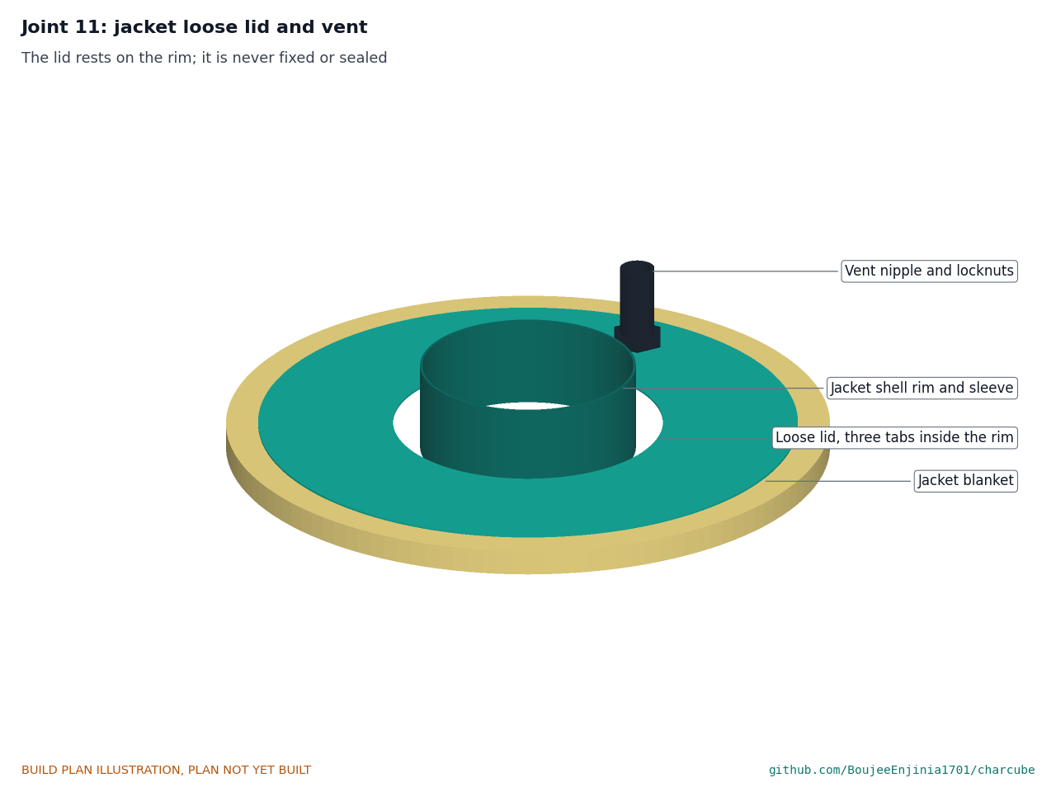
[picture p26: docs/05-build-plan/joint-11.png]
Figure 16. Joint 11: jacket loose lid and vent


*Figure 16. The lid rests on the shell rim, located by its tabs; it is never fixed, sealed or weighted.*

**Check before moving on.** The lid lifts off by hand, and the vent and centre hole are clear.

### 3.14 Jacket blanket

**What it is and what it is made from.** Bought 25 mm mineral wool (rock wool) blanket that keeps the heat in the water; the jacket's outside stays below 100 °C, so mineral wool is enough.

**How to make it.** Wearing a dust mask, cut a strip 540 wide and about 1.42 m long. Cut it round the tap.

**How it fits the parts next to it.** It wraps the jacket from 60 above its bottom (above the fins and the tap) to the rim, held by tie wire.

**Check before moving on.** The tap, vent and lid are clear of the blanket.

### 3.15 Tripod legs (make 3)

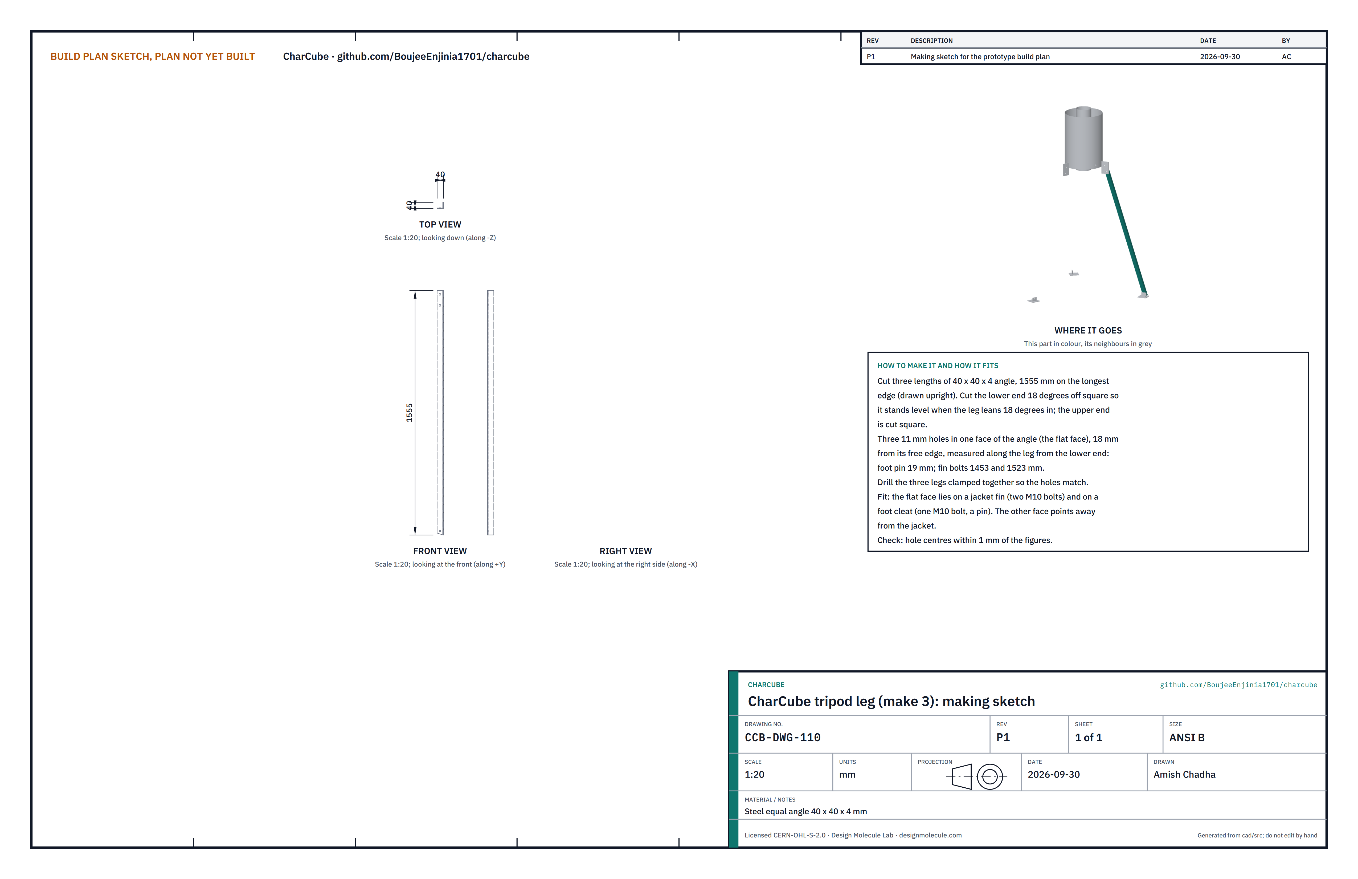
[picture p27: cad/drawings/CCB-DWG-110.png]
Figure 17. Making sketch of the tripod leg


*Figure 17. Tripod leg making sketch (CCB-DWG-110), drawn upright.*

**What it is and what it is made from.** The three legs that carry the jacket, water and flue over the kiln so the drum's lid carries no water load. Steel equal angle, 40 x 40 x 4.

**How to make it.**

1. Cut three lengths, 1579 on the longest edge. Cut the lower end 18 degrees off square, so it stands level when the leg leans 18 degrees in; cut the upper end square.
2. On one face of the angle (the flat face), on a line 18 from its free edge, drill three 11 holes, measured along the leg from the middle of the lower end: 19 (the foot pin), 1477 and 1547 (the fin bolts).
3. Drill the three legs clamped together so the holes match.

**How it fits the parts next to it.**

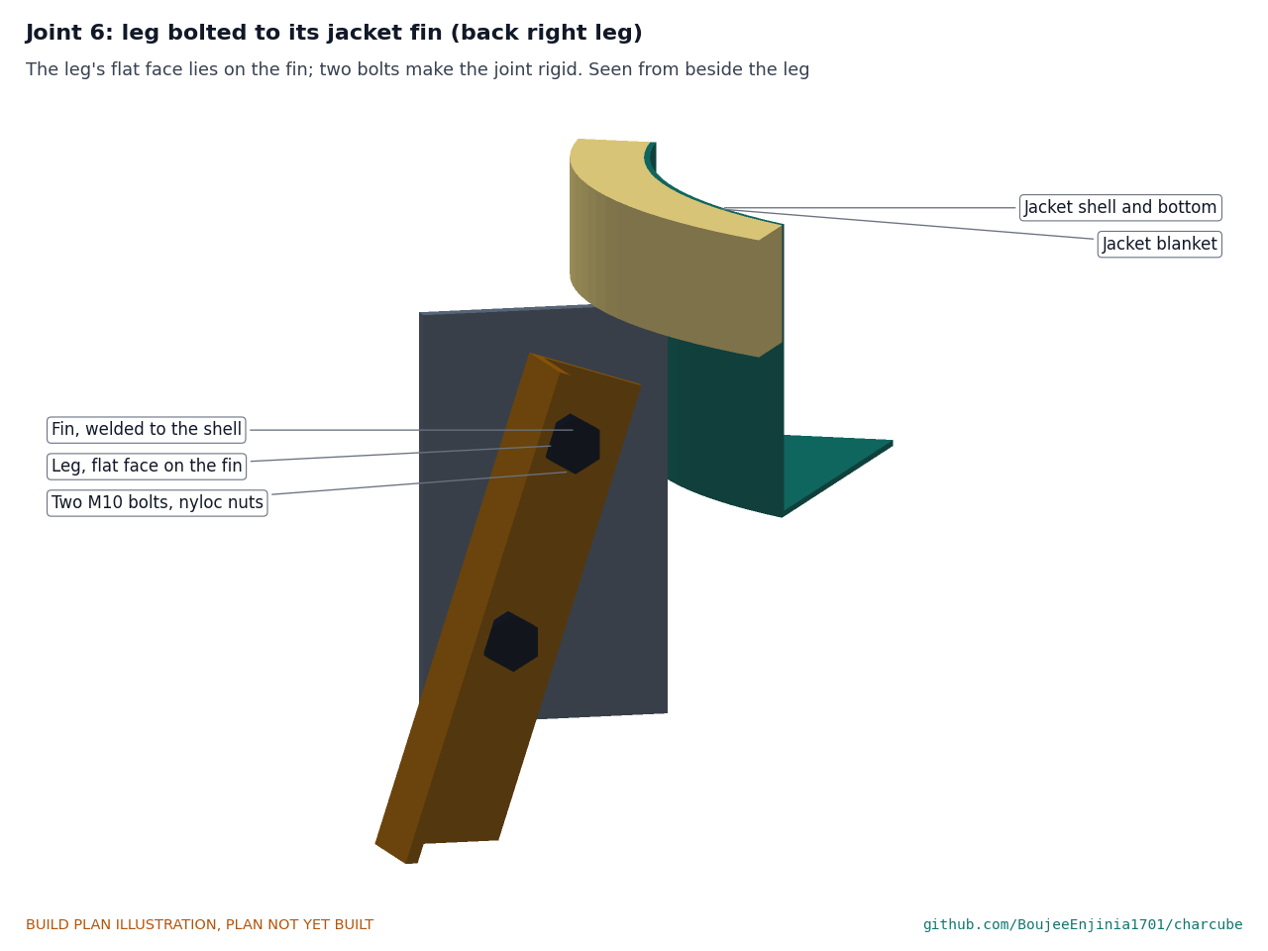
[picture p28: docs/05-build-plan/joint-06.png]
Figure 18. Joint 6: leg bolted to its jacket fin


*Figure 18. The leg's flat face lies on the fin; two M10 bolts make the joint rigid.*

The flat face lies against the side of a fin, the other face pointing away from the jacket, with two M10 bolts and nyloc nuts. The leg stays 21 clear of the jacket blanket and 40 clear of the drum blanket.

The legs and their feet are what the heat-recovery unit stands on when the lifting aid sets it down (section 3.22); the unit is never carried by its legs.

**Check before moving on.** Hole centres within 1 of the figures.

### 3.16 Foot cleats and pads (make 3 sets)

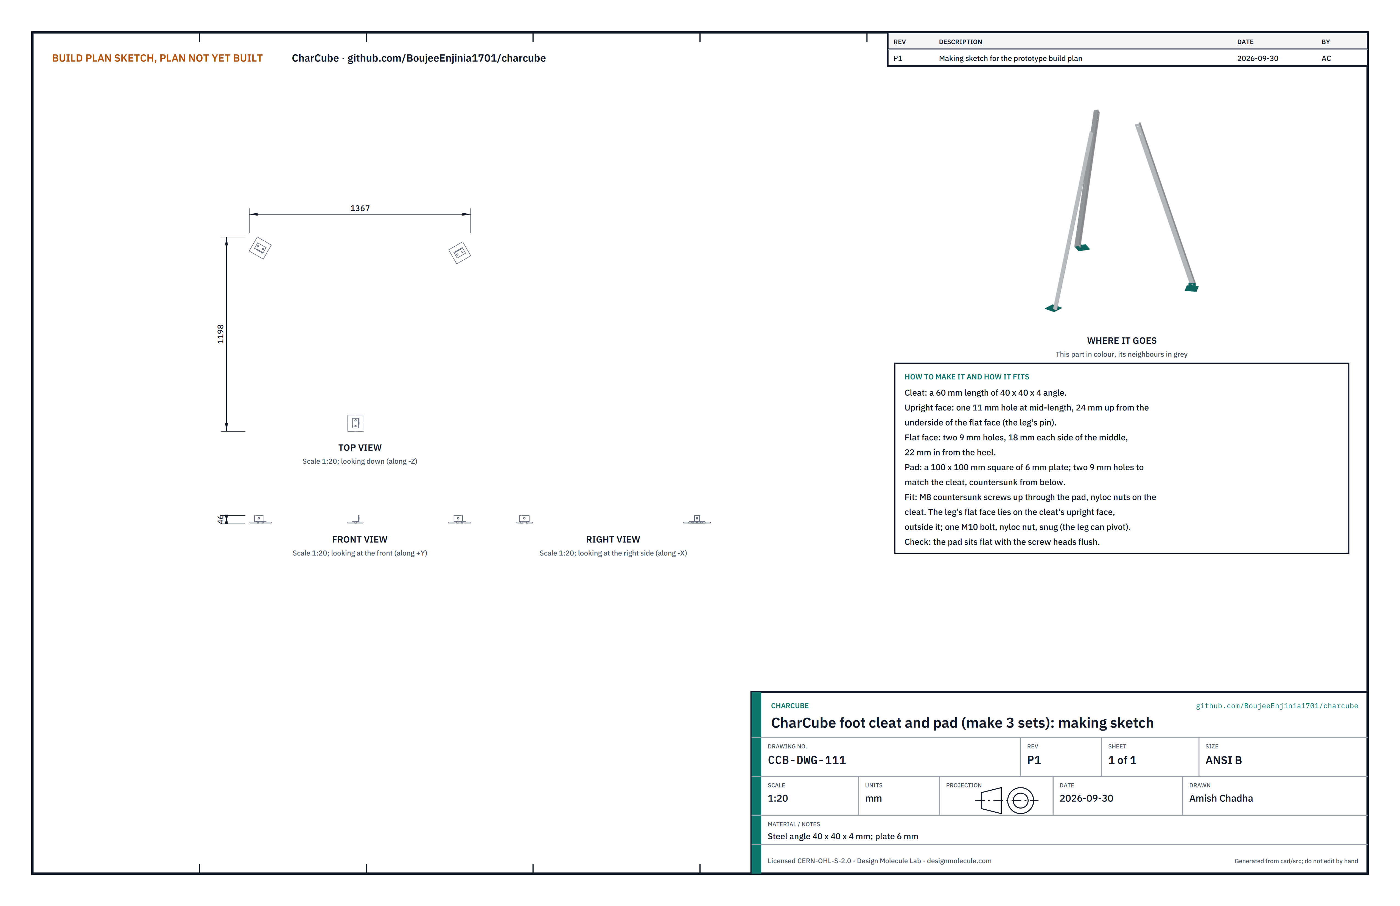
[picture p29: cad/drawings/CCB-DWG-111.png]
Figure 19. Making sketch of the foot cleat and pad


*Figure 19. Foot cleat and pad making sketch (CCB-DWG-111).*

**What it is and what it is made from.** A short cleat of the leg angle on a steel foot pad, so each leg stands on a broad, flat foot. Angle 40 x 40 x 4, plate 6.

**How to make it.**

1. Cut three cleats 60 long. In the upright face, drill one 11 hole at mid-length, 24 up from the underside of the flat face. In the flat face, drill two 9 holes, 18 each side of the middle and 22 in from the heel.
2. Cut three pads 100 x 100 from 6 plate; drill two 9 holes to match the cleat and countersink them from below.
3. Screw each cleat to its pad with two M8 countersunk screws from below and nyloc nuts on top.

**How it fits the parts next to it.**

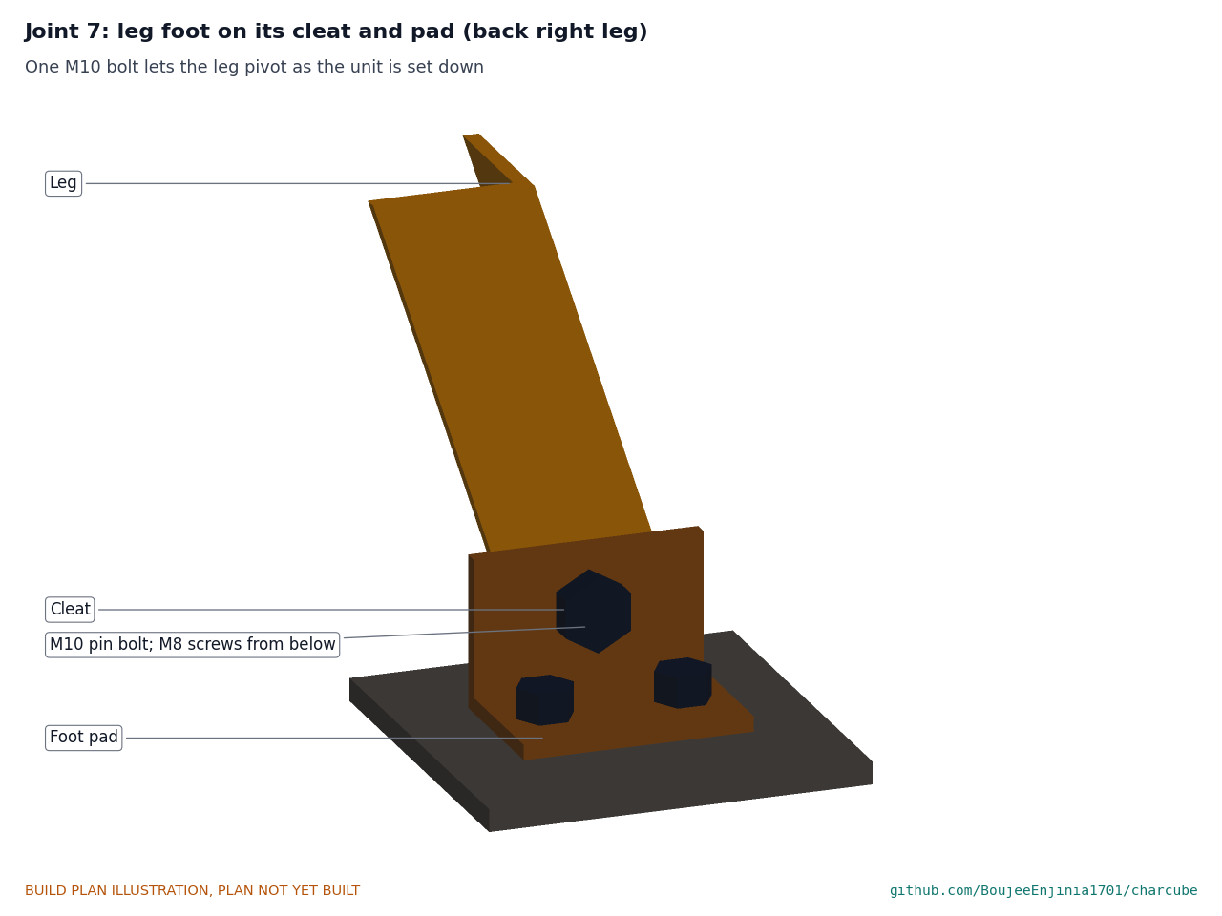
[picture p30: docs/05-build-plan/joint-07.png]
Figure 20. Joint 7: leg foot on its cleat and pad


*Figure 20. One M10 bolt pins the leg to the cleat, so the leg can settle as the unit is set down.*

The leg's flat face lies on the cleat's upright face, outside it; one M10 bolt with a nyloc nut, snug. The foot centres sit on a 1.44 m circle. The pin lets each leg settle as the lifting aid lowers the unit onto its feet, beside the kiln or over it.

**Check before moving on.** Each pad sits flat with the screw heads flush.

### 3.17 Flue and stop clips

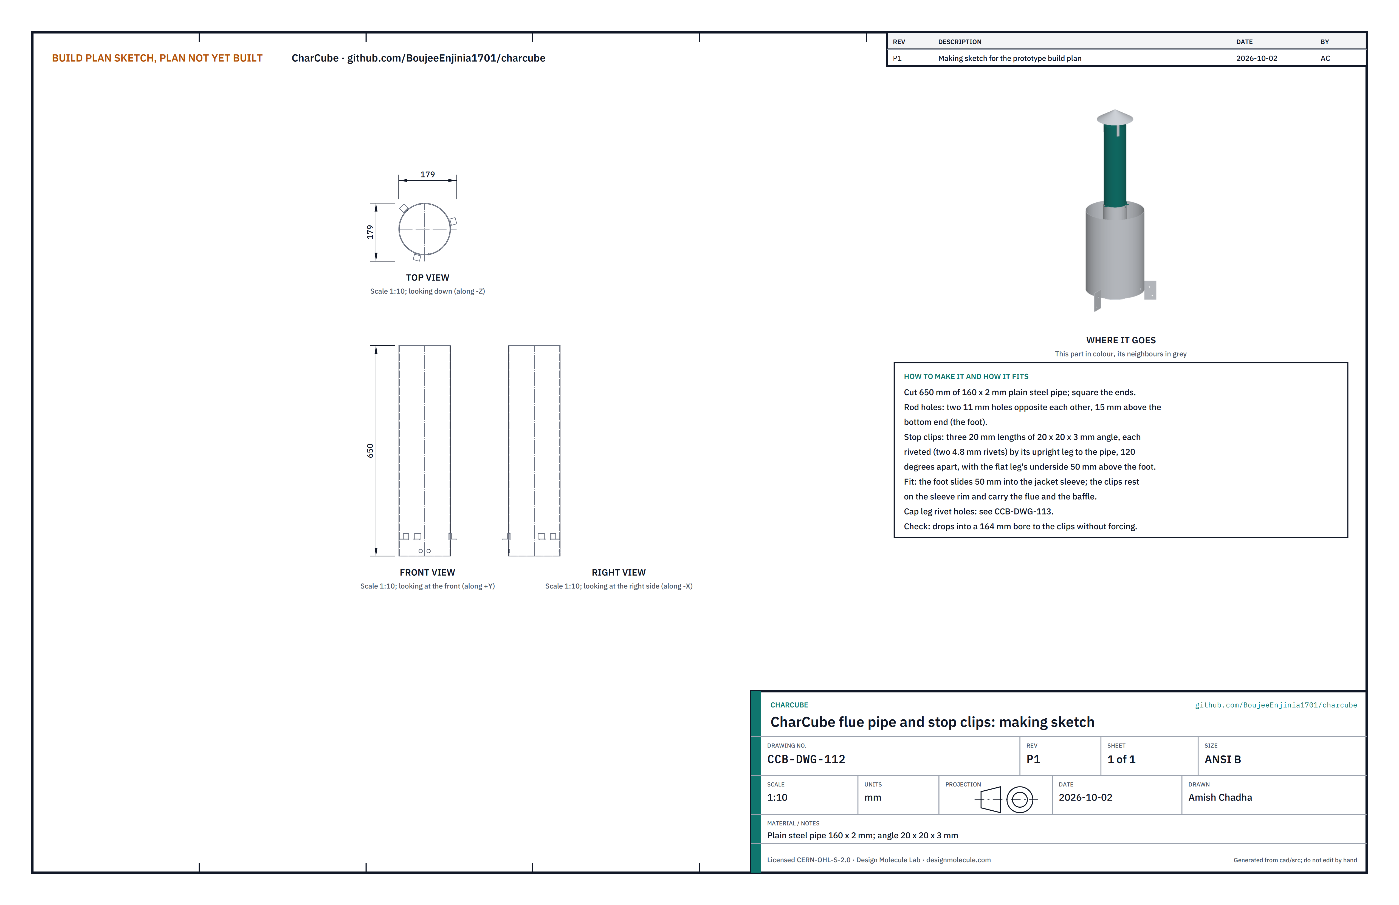
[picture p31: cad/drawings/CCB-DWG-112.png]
Figure 21. Making sketch of the flue pipe


*Figure 21. Flue pipe and stop clips making sketch (CCB-DWG-112).*

**What it is and what it is made from.** A 650 length of 160 x 2 plain steel pipe that carries the gas from the jacket to the outlet, 2.72 m above the ground. Three clips of 20 x 20 x 3 angle seat it on the jacket.

**How to make it.**

1. Cut 650 of pipe and square the ends. The lower end is the foot.
2. Drill two 11 holes opposite each other, 15 above the foot, for the baffle rod.
3. Cut three clips 20 long. Rivet each by its upright leg to the pipe with two 4.8 rivets, 120 degrees apart, with the underside of its flat leg 50 above the foot.

**How it fits the parts next to it.**

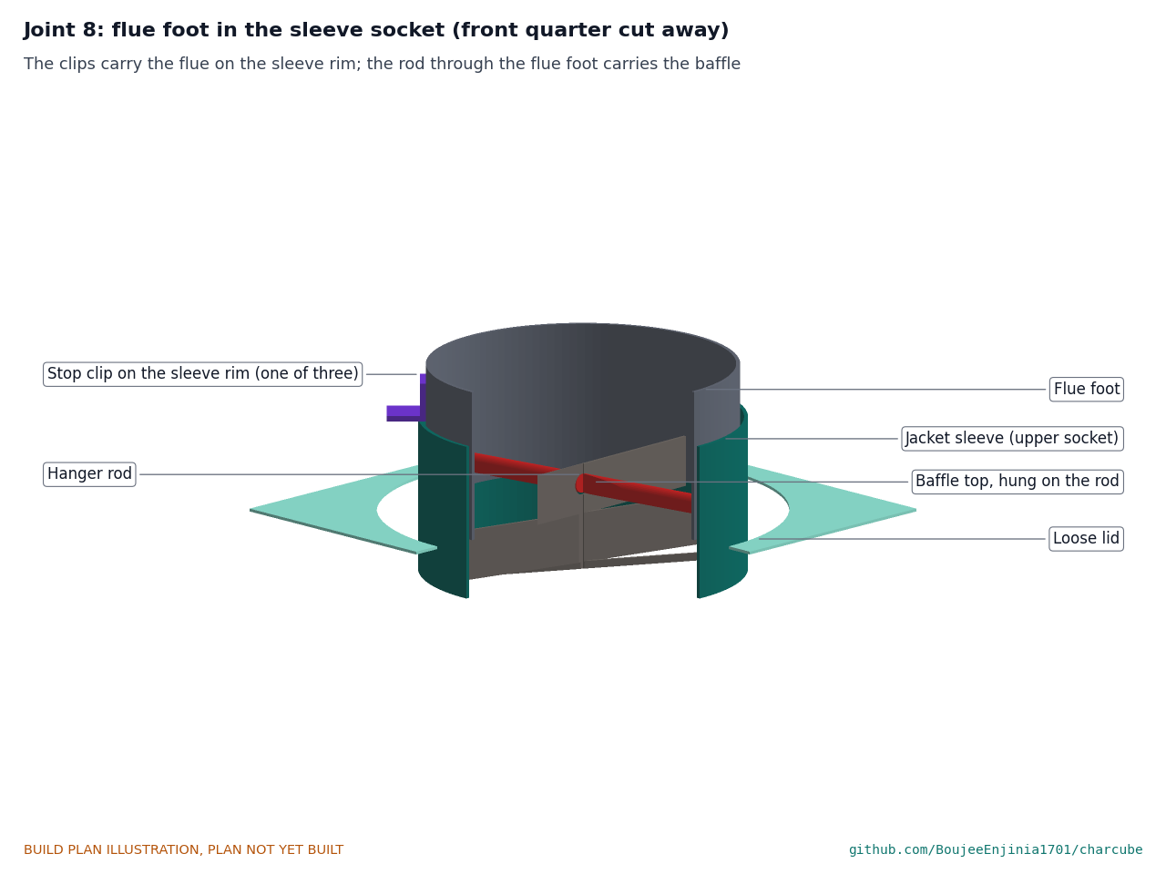
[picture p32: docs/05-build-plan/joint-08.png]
Figure 22. Joint 8: flue foot in the sleeve socket


*Figure 22. The flue's foot sits 50 mm down the sleeve with 2 mm clear; its three clips rest on the sleeve rim; the rod through the foot carries the baffle.*

**Check before moving on.** The pipe drops into the sleeve to its clips without forcing.

### 3.18 Rain cap and legs

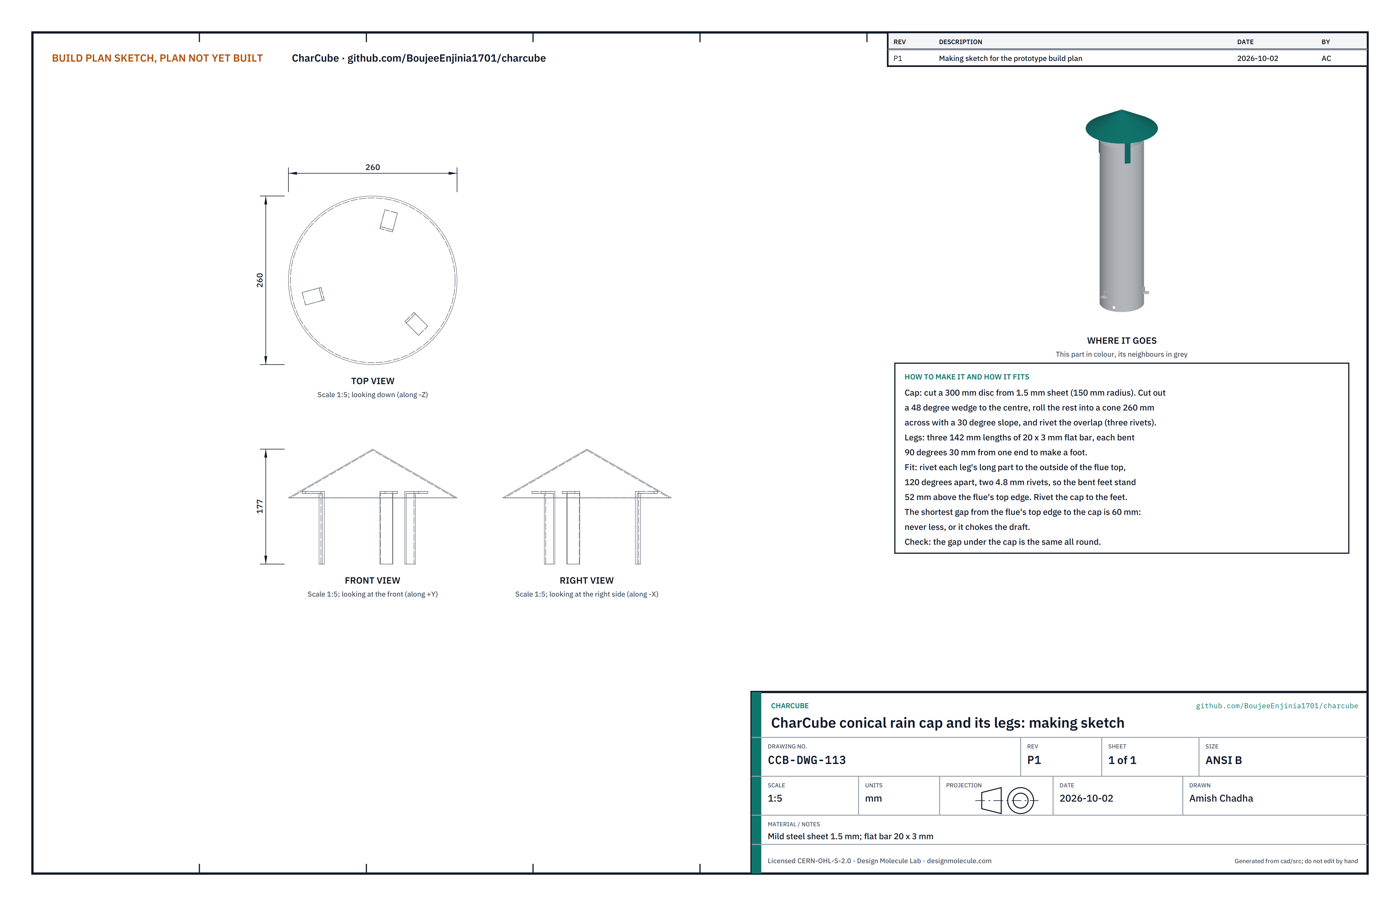
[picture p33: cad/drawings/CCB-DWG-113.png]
Figure 23. Making sketch of the conical rain cap and legs


*Figure 23. Conical rain cap and legs making sketch (CCB-DWG-113).*

**What it is and what it is made from.** A cone of 1.5 mm sheet, 260 across with a 30 degree slope, on three legs of 20 x 3 flat bar, keeping rain out of the flue.

**How to make it.**

1. Cut a 300 disc from 1.5 sheet. Cut out a 48 degree wedge to the centre, roll the rest into a cone 260 across and rivet the overlap with three 4.8 rivets.
2. Cut three legs 142 long and bend each 90 degrees 30 from one end to make a foot.
3. Rivet the legs to the outside of the flue top, 120 degrees apart, two 4.8 rivets each, with the bent feet 52 above the flue's top edge. Rivet the cone to the feet.

**How it fits the parts next to it.**

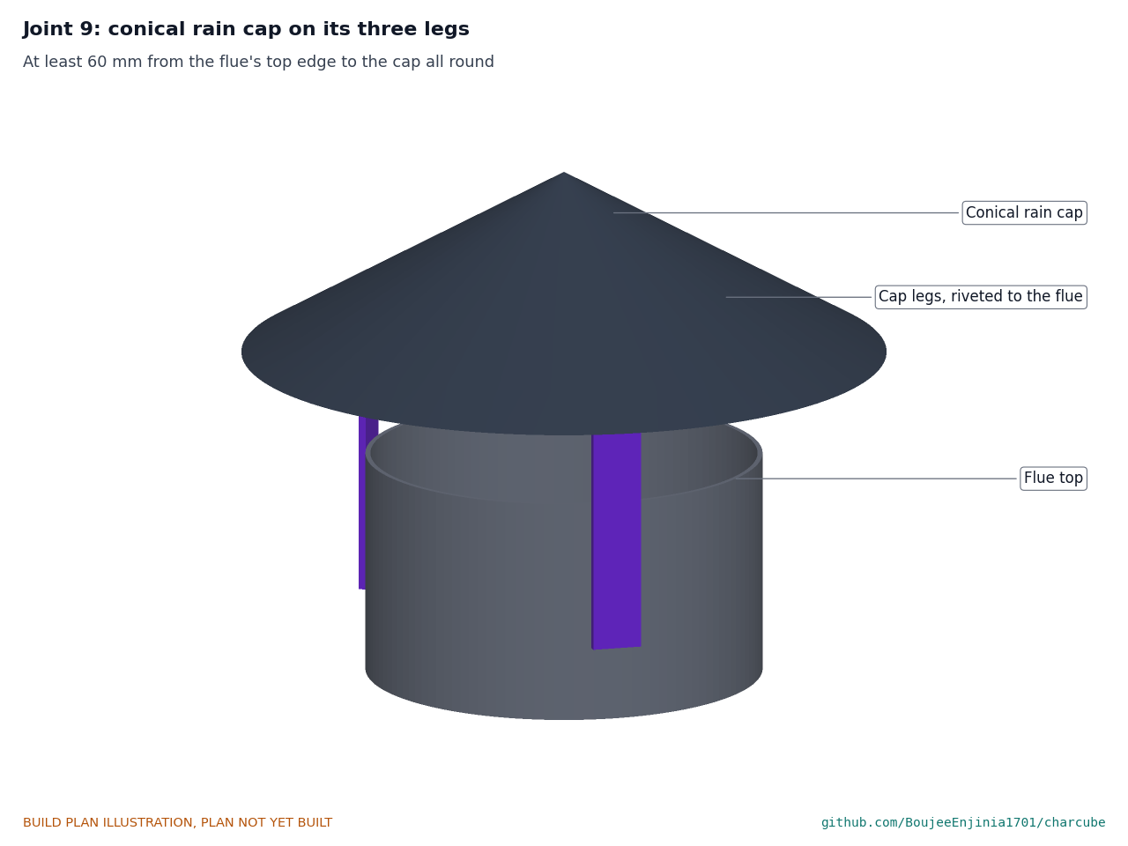
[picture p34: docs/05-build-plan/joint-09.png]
Figure 24. Joint 9: rain cap on its three legs


*Figure 24. The shortest gap from the flue's top edge to the cone is 60 mm all round: less than that chokes the draft.*

**Check before moving on.** The gap under the cap is the same all round.

### 3.19 Spiral baffle and hanger rod

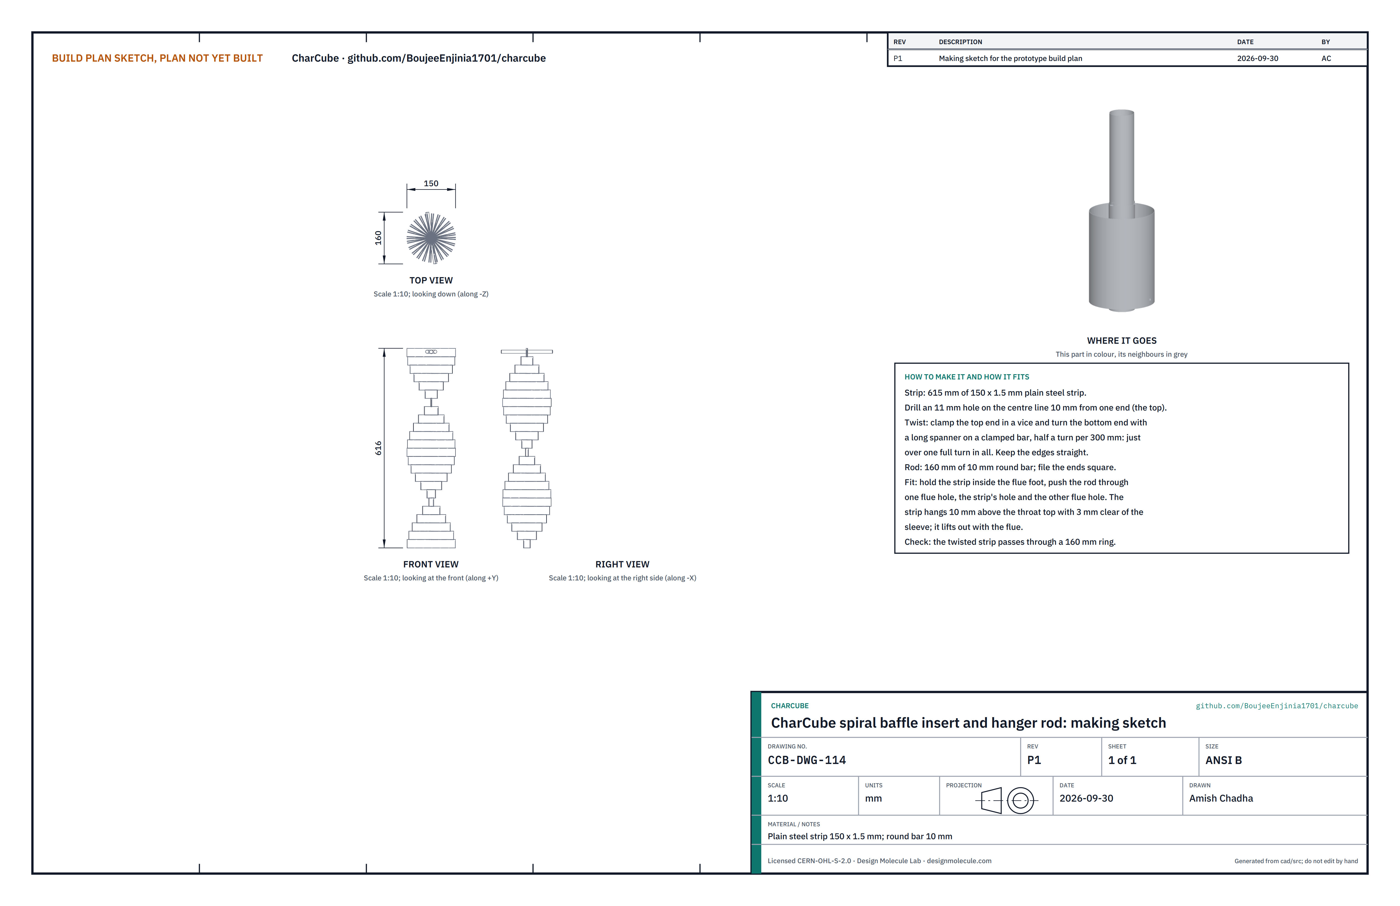
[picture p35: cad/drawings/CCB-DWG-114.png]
Figure 25. Making sketch of the spiral baffle and rod


*Figure 25. Spiral baffle insert and hanger rod making sketch (CCB-DWG-114).*

**What it is and what it is made from.** A twisted strip of 150 x 1.5 plain steel that swirls the gas against the sleeve wall so more heat reaches the water, hung on a 10 mm steel rod.

**How to make it.**

1. Cut 615 of strip. Drill an 11 hole on its centre line, 10 from one end (the top).
2. Clamp the top end in a vice, clamp a bar across the bottom end and turn it with a long spanner: half a turn for every 300, just over one full turn in all. Keep the edges straight.
3. Cut 160 of 10 round bar and file the ends square.

**How it fits the parts next to it.** Hold the strip inside the flue foot, push the rod through one flue hole, the strip's hole and the other flue hole (Figure 22). The strip hangs down the sleeve 3 clear of its wall, its bottom 10 above the throat (Figure 14), and lifts out with the flue for cleaning.

**Check before moving on.** The twisted strip passes through a 160 ring along its whole length.

### 3.20 Logger and probes

**What it is and what it is made from.** Bought: a weatherproof box with a small microcontroller, three thermocouple amplifiers, a microSD card and a USB power bank; two type K class 1 probes with 6 stainless sheaths, 500 long (retort core) and 300 long (throat exit); and the block thermocouple, a bare-wire type K with glass-fibre insulation and a 1 m lead (section 3.1).

**How to make it.** Wire the three amplifiers to the microcontroller as their makers describe and lead the probe cables through cable glands in the box. The logging program is not part of this plan.

**How it fits the parts next to it.**

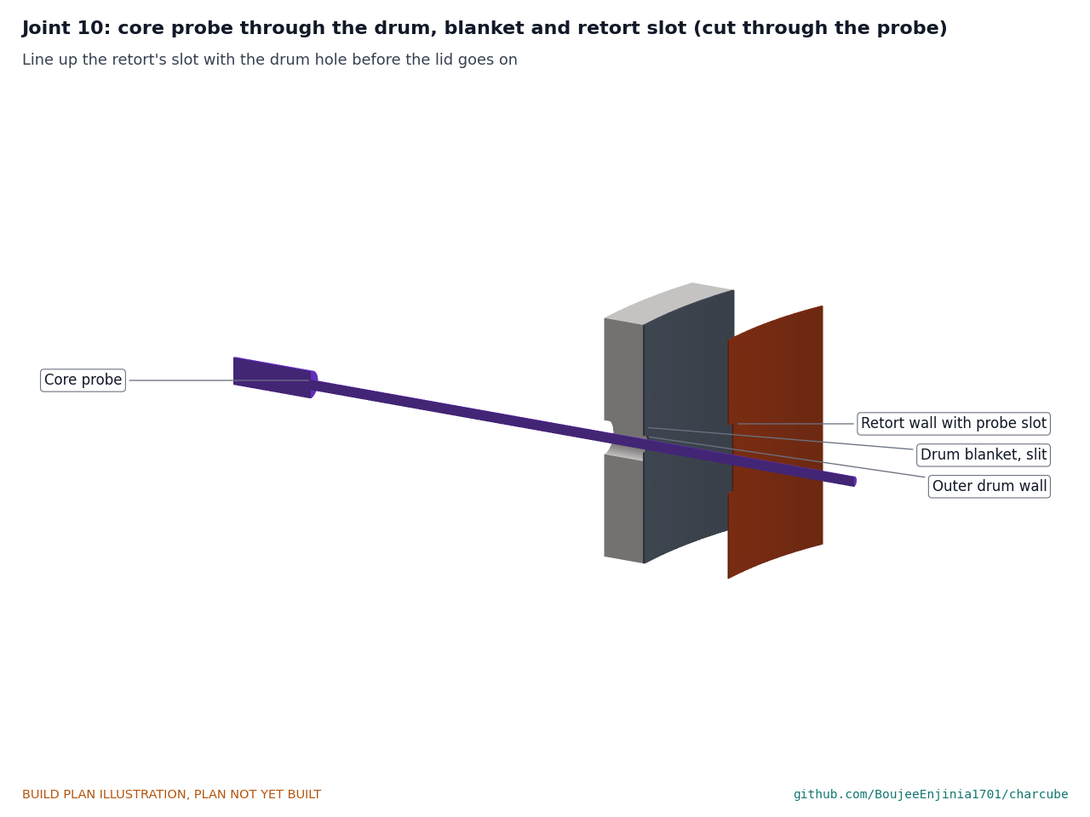
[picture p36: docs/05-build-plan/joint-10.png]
Figure 26. Joint 10: core probe through the drum, blanket and retort slot


*Figure 26. The core probe passes through the drum's 10 mm hole and the blanket slit, crosses the 43 mm gas gap and enters the retort through its slot to the middle of the charge.*

The core probe goes in at the back, 361 above the drum floor, until its tip reaches the retort's axis. The throat probe goes into the throat's 8 hole at the back, 70 below the jacket, until its tip reaches the throat's axis. The box is strapped with two stainless hose clips beside the back right leg, 520 above the ground, away from the heat; probe cables are rated for the temperature where they run.

**Check before moving on.** All three channels read room temperature, within 5 °C of a reference thermometer.

### 3.21 Bought components

Buy to specification, not brand. Line numbers are those of the bill of materials.

- **Drums (lines 1 and 3).** A 200 L open-head steel drum with lid and locking ring, about 572 across, and a 114 L open-head drum with bolt-ring lid, about 463 across, both that held non-flammable, non-toxic products only. Check the gap between them is at least 40 all round.
- **Firebricks (line 4).** Three half firebricks, about 114 x 64 x 60.
- **Pipe (lines 6 and 7).** Plain (not galvanized) steel pipe, 160 outside diameter, 2 wall: 400 for the throat and 650 for the flue.
- **Tap (line 9).** 1/2 in brass ball valve and nipple.
- **Blankets (lines 11, 16 and 17).** 25 mm ceramic fibre blanket, 128 kg/m³, about 2.6 m² in all for the drum and lid; 25 mm mineral wool blanket, about 0.8 m², for the jacket; wire mesh and tie wire.
- **Plinth (line 12).** Four 390 x 190 x 190 concrete blocks and a 600 x 900 sheet of 25 mm ceramic fibre board, 1260 °C grade.
- **Logger (line 13).** As section 3.20.
- **Fixings and consumables (line 14).** 4.8 steel rivets (about 80); nine M10 x 30 bolts and six M8 x 20 countersunk screws, with nyloc nuts and washers; two M8 U-bolts, legs 80 apart; one M6 wing screw and rivet nut; ceramic gasket rope; high-temperature sealant; tie wire; two stainless hose clips; high-temperature paint.
- **Hot-surface labels (line 14).** Two ISO 7010 W017 hot-surface warning signs, 100 mm aluminium triangles with two holes. Wire one to the drum blanket's mesh and one to the jacket blanket, both at the front right where the operator stands (Figure 27). Check after each season that they are still there and readable.

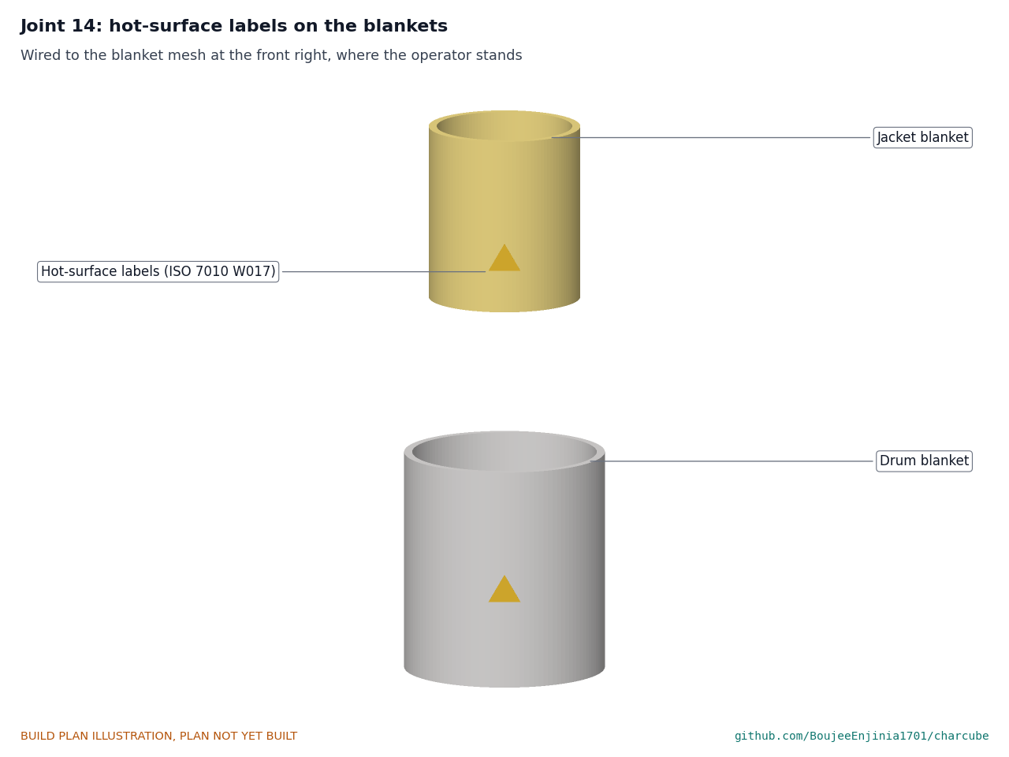
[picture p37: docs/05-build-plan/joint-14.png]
Figure 27. The two hot-surface labels on the drum blanket and the jacket blanket


*Figure 27. The two hot-surface labels, at the front right of the drum blanket and of the jacket blanket.*

### 3.22 Lifting aid

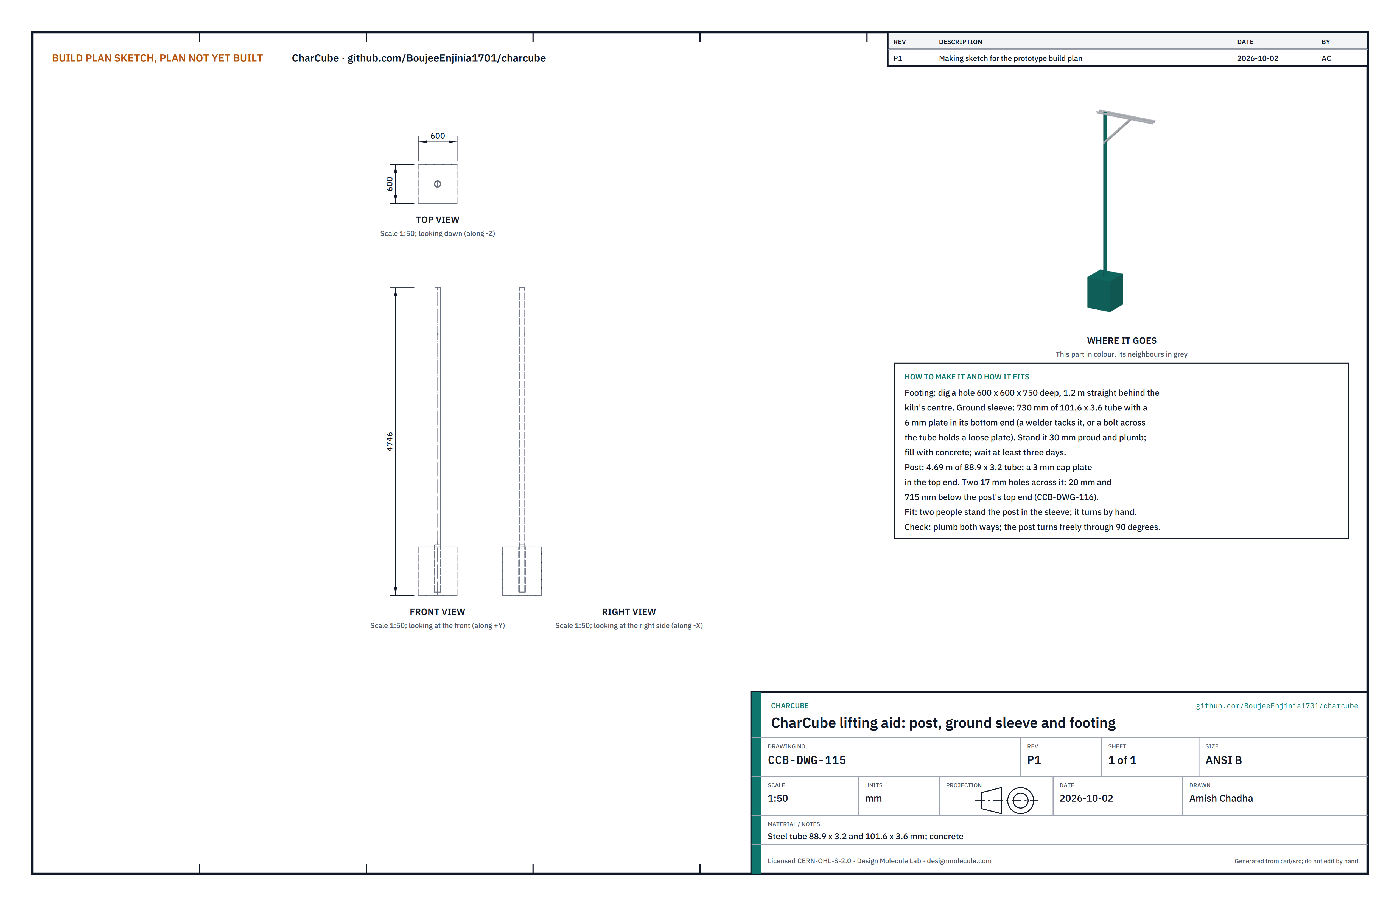
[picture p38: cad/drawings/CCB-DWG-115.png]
Figure 28. Making sketch of the lifting aid post, ground sleeve and footing


*Figure 28. Lifting aid post, ground sleeve and footing making sketch (CCB-DWG-115).*

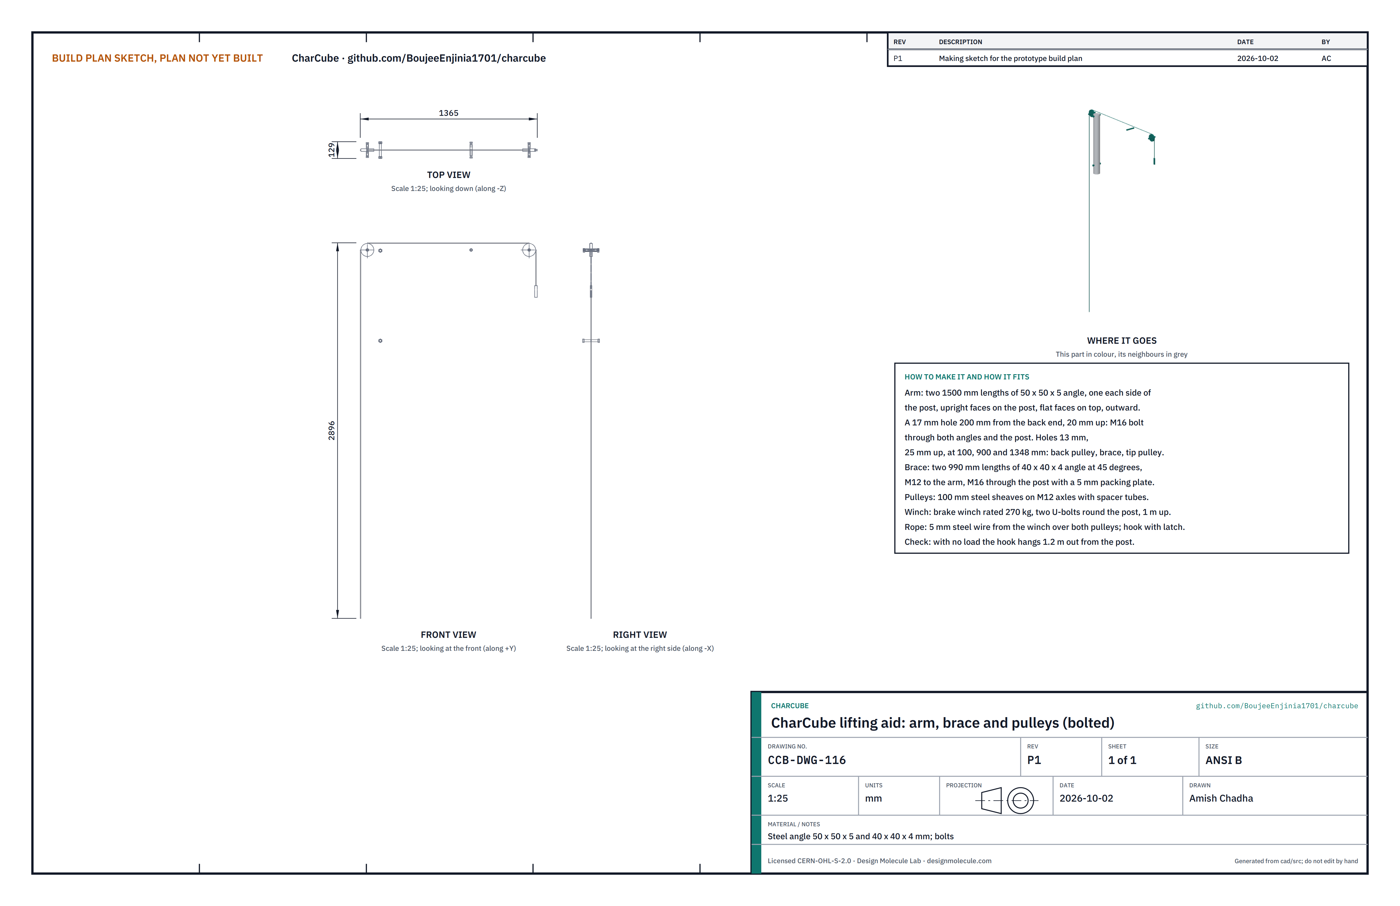
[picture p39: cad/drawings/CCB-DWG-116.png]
Figure 29. Making sketch of the lifting aid arm and brace


*Figure 29. Lifting aid arm, brace and pulleys making sketch (CCB-DWG-116).*

**What it is and what it is made from.** A post that turns in a sleeve set in the ground, with an arm on top and a hand winch, so that the drained heat-recovery unit (about 47 kg) is wound up, swung clear of the kiln and set down, and nobody carries it. Steel tube 88.9 x 3.2 and 101.6 x 3.6, angle 50 x 50 x 5 and 40 x 40 x 4, two 100 steel pulleys, a hand brake winch rated 270 kg, 5 mm steel wire rope, a hook with a safety latch, a 16 round bar and concrete. It is bolted; nothing on it is welded except the plate in the bottom of the ground sleeve, which can be a loose plate held by a bolt instead.

**How to make it.**

1. Footing: dig a hole 600 x 600 and 750 deep with its centre 1.2 m straight behind the kiln's centre. Stand the ground sleeve (730 of 101.6 tube with its bottom closed) in it, 30 proud of the ground and plumb, and fill the hole with concrete. Leave it at least three days before loading it.
2. Post: cut 4.69 m of 88.9 tube; close the top end with a 3 mm plate. Drill two 17 holes straight across it, 20 and 715 below its top end, as on Figure 28.
3. Arm: cut two lengths of 50 x 50 x 5 angle, 1500. Drill each as on Figure 29: a 17 hole for the post bolt, 200 from the back end, and 13 holes for the back pulley, the brace and the tip pulley.
4. Brace: cut two lengths of 40 x 40 x 4 angle, 990, and drill a hole near each end; cut two 5 mm packing plates for the brace's lower end.
5. Lift bar: cut 230 of 16 round bar.

**How it fits the parts next to it.**

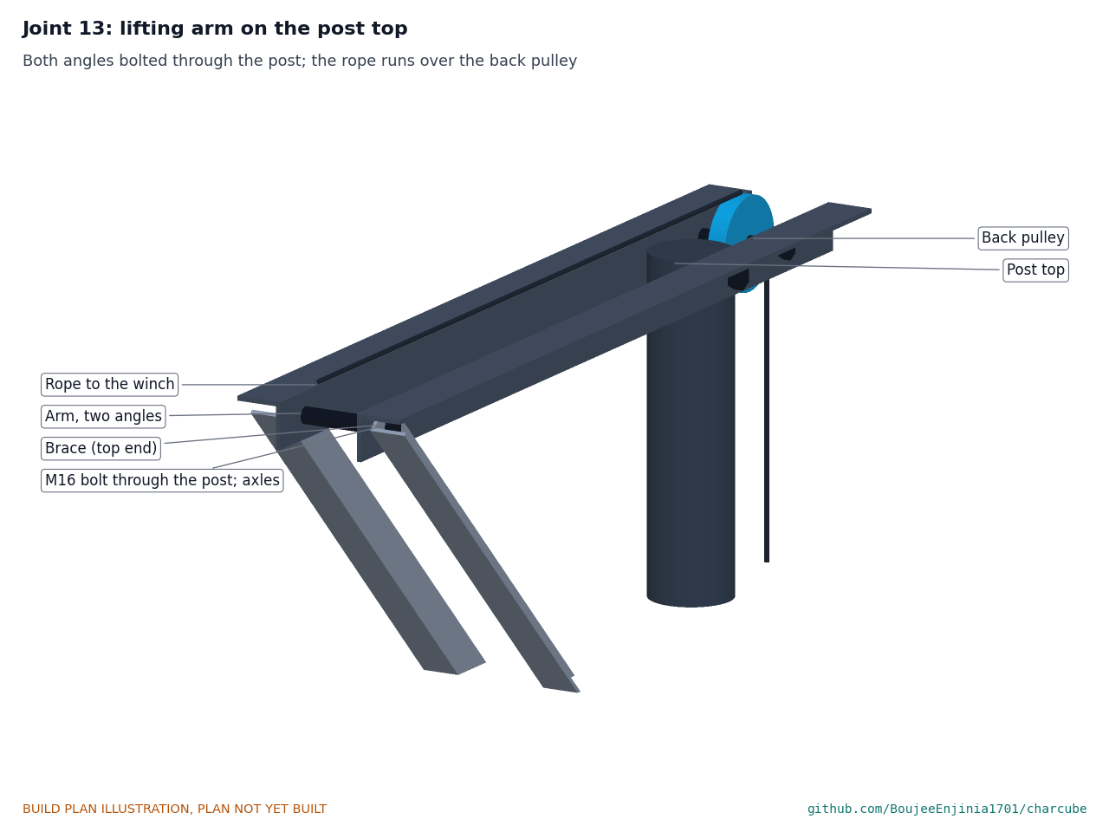
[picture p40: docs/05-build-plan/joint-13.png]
Figure 30. Joint 13: the arm on the post top


*Figure 30. The two arm angles are bolted through the post with one M16 bolt; the brace runs down to a second M16 bolt; the rope runs from the winch over the back pulley and along the arm to the tip pulley.*

Two people stand the post in its sleeve (about 16 kg each). From a stepladder, bolt the two arm angles either side of the post top, then the brace angles with their packing plates, then the pulleys on their axles between the arm angles with spacer tubes. Bolt the winch to the post 1 m above the ground with two U-bolts on the side away from the arm, and reeve the rope from the winch over the back pulley, along the arm and over the tip pulley to the hook. With the arm turned toward the kiln, the hook hangs over the kiln's centre; parked, the arm points to the left, away from the flue.

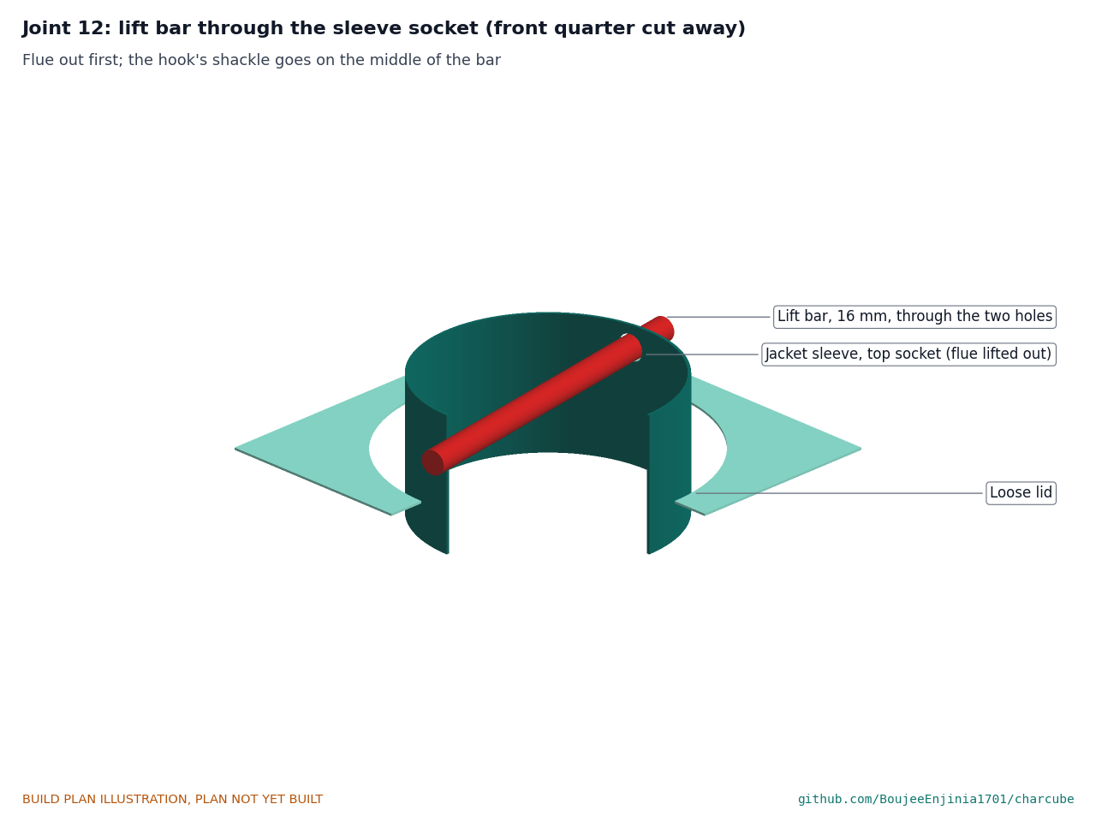
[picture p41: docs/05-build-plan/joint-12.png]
Figure 31. Joint 12: the lift bar through the jacket sleeve's top socket


*Figure 31. With the flue lifted out, the lift bar goes through the two holes in the sleeve's top socket; the hook's shackle goes on its middle.*

**Check before moving on.** The post turns by hand through a quarter turn; the winch holds a load with the handle let go; with the unit hanging 100 off the ground, the post leans no more than about 50 at its top.

## 4. Putting it together

In each picture the parts already fitted are grey and the part being fitted is in colour, with an arrow showing the way it goes in.

### Step 1: lay the plinth

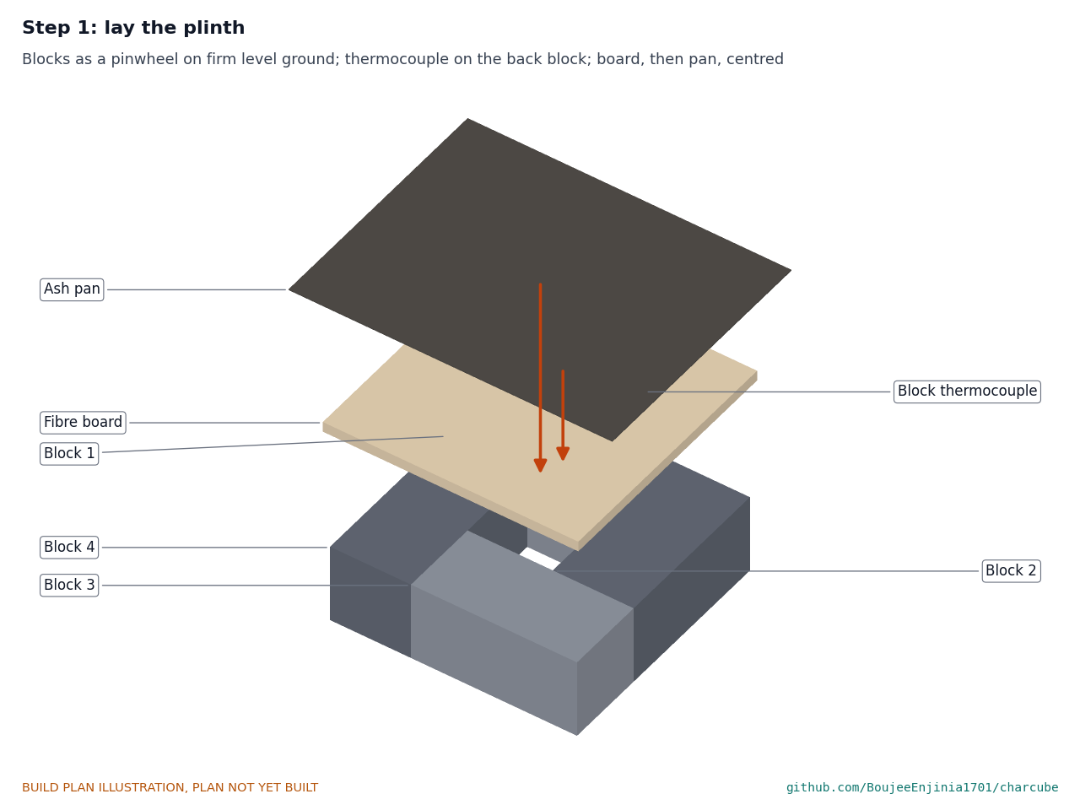
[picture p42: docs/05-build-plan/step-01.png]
Step 1


On firm, level, bare soil or paving at least 5 m from anything that can burn, 1.2 m in front of the lifting aid's post (section 3.22; pour its footing first so the concrete has set by step 15). Lay the four blocks as a pinwheel, lay the block thermocouple's tip on the back block, then the fibre board, groove down over the lead, and the pan on top, centred.

### Step 2: fit the port dampers and guides

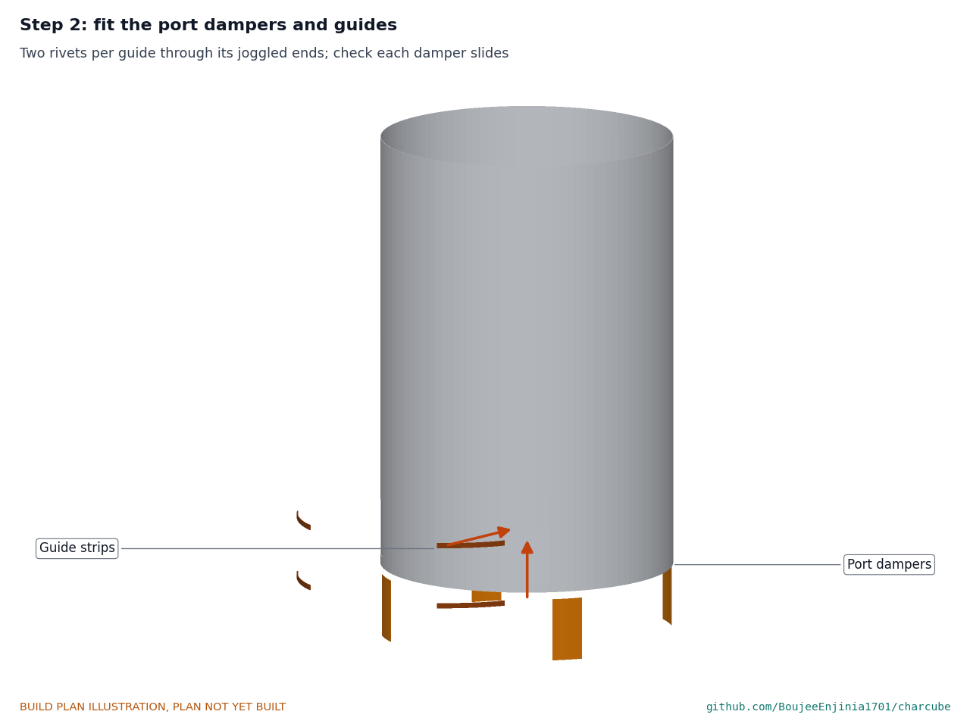
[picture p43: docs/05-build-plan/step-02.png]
Step 2


With the drum on its side on a bench, rivet two guides per port through their joggled ends with each damper in place between them. Check every damper slides.

### Step 3: stand the drum on the ash pan

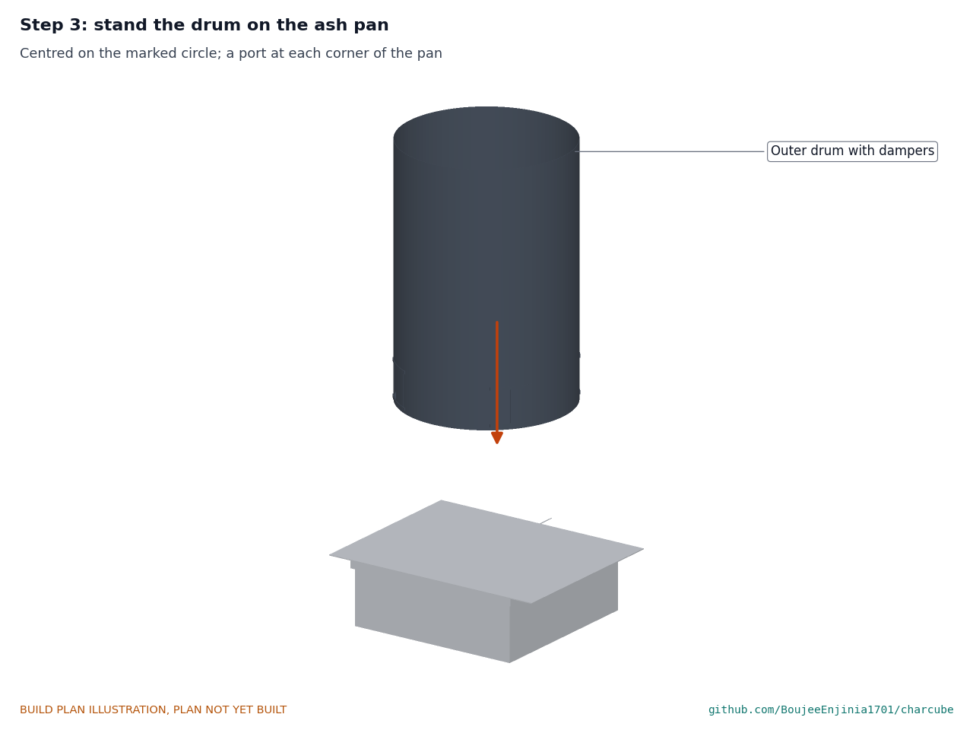
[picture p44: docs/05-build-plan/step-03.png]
Step 3


Centred on the marked circle, with a port toward each corner of the pan.

### Step 4: wrap the drum blanket

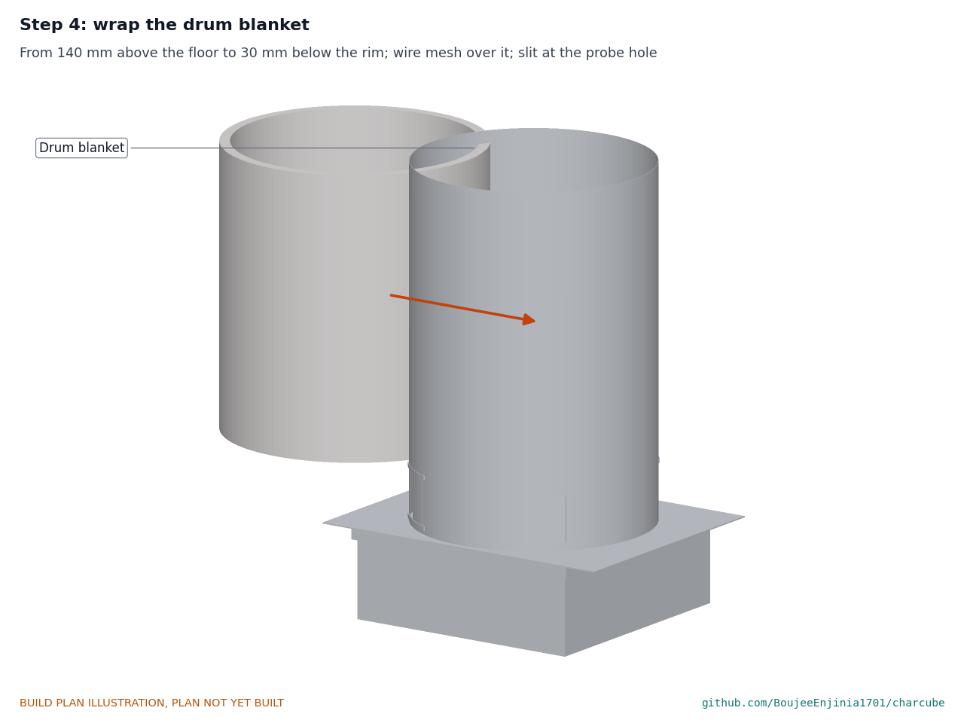
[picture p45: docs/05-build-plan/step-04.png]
Step 4


From 140 above the floor to 30 below the rim; wire mesh over it, twisted tight. Slit at the probe hole.

### Step 5: set the bricks in the drum

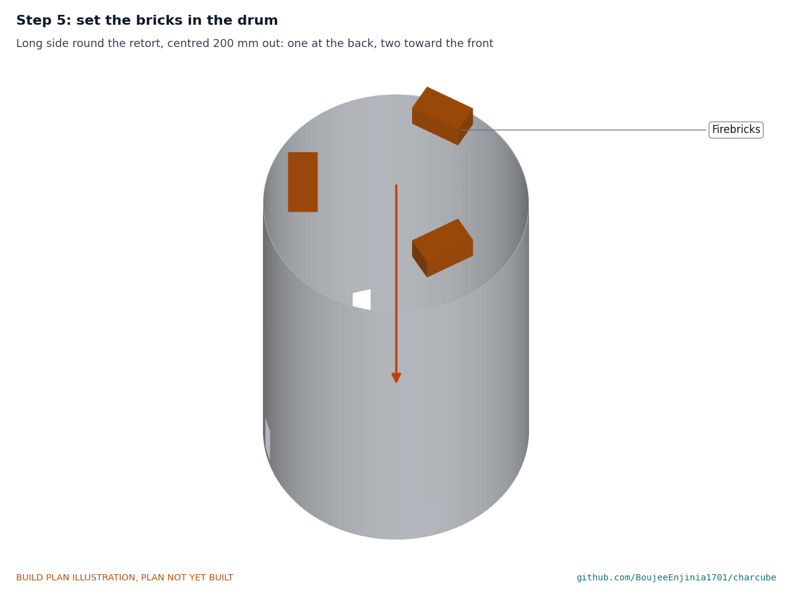
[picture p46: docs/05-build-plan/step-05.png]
Step 5


Long side round the drum, centred 200 out: one at the back, two toward the front.

### Step 6: lower the retort onto the bricks

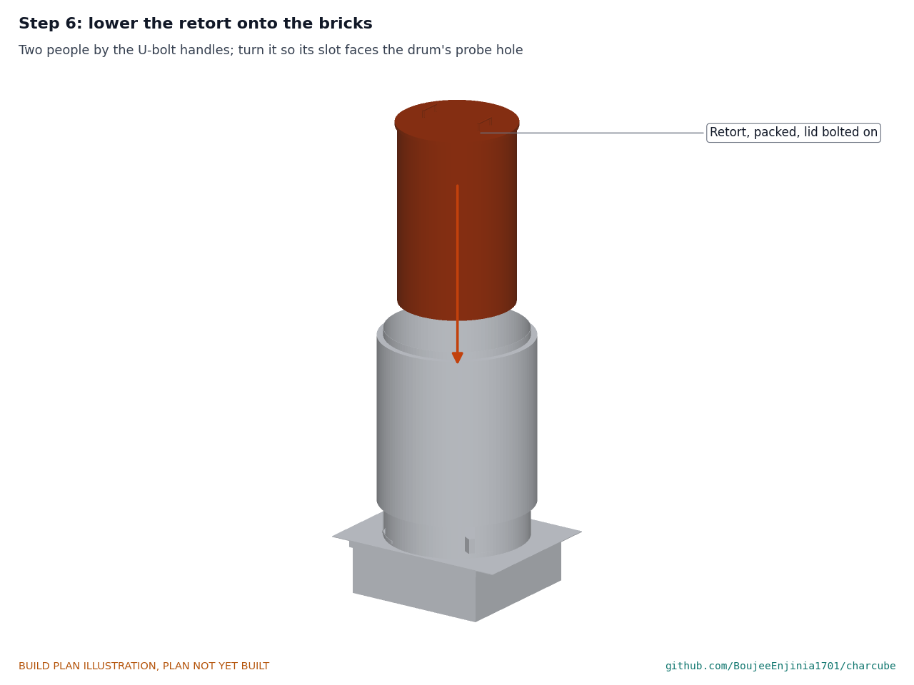
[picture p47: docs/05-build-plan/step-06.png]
Step 6


Pack the retort with residue to 600 and bolt its lid on. Two people lower it by the U-bolt handles, turned so the punch mark on its rim faces the drum's probe hole at the back. **Hold point:** the gas gap is even all round (at least 40) and the slot lines up with the probe hole.

### Step 7: collar and throat onto the lid

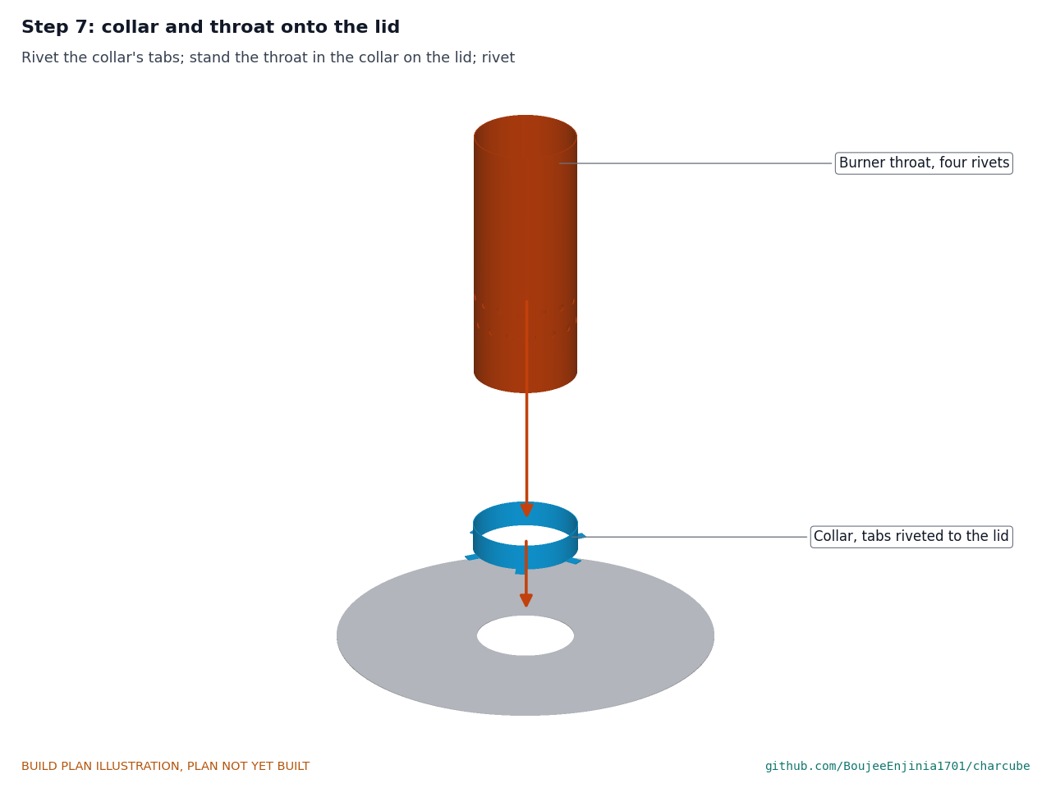
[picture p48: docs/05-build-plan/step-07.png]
Step 7


Rivet the collar's tabs to the lid; stand the throat in the collar on the lid; rivet the throat to the collar.

### Step 8: air shroud and band onto the throat

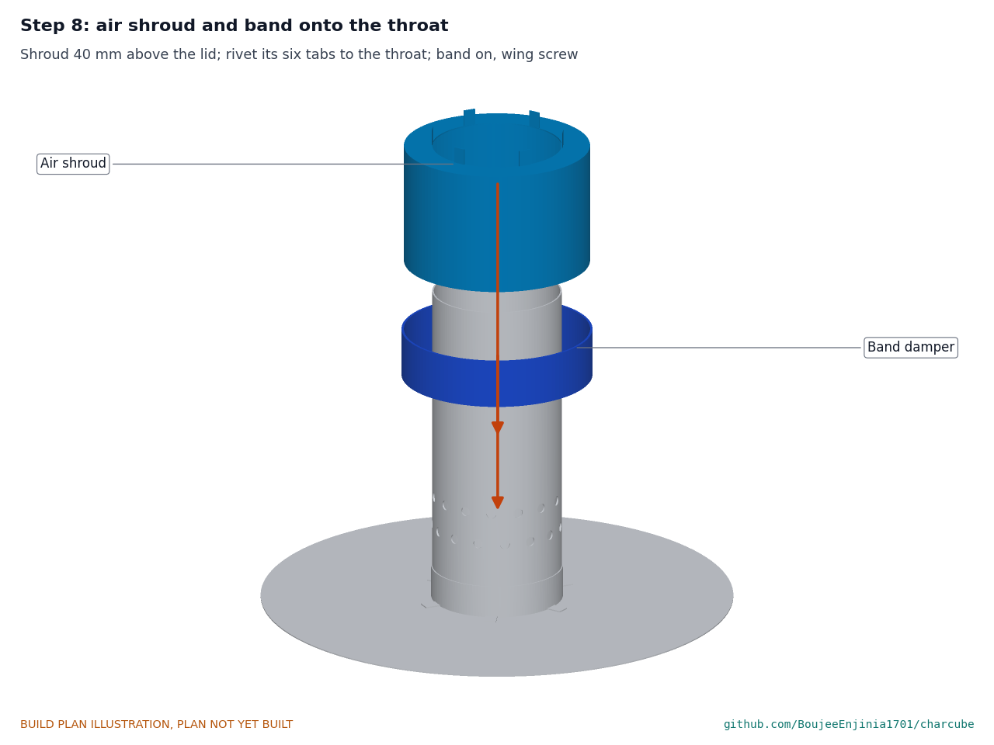
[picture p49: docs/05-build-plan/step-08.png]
Step 8


Shroud on a 40 spacer, tabs riveted to the throat; band on the shroud, wing screw tight.

### Step 9: lid blanket onto the lid

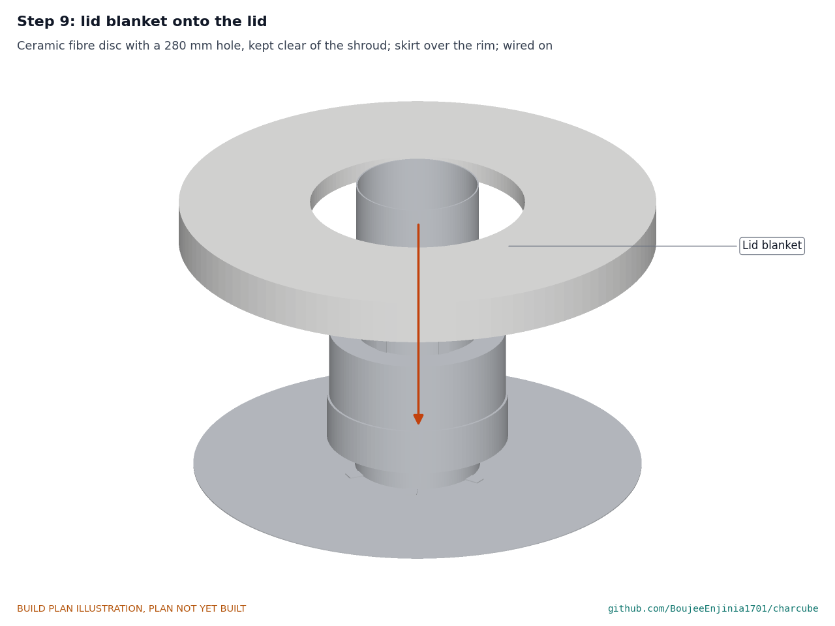
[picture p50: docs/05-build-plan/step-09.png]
Step 9


Ring round the shroud, 25 clear of it; skirt over the rim; tie wire.

### Step 10: lid unit onto the drum

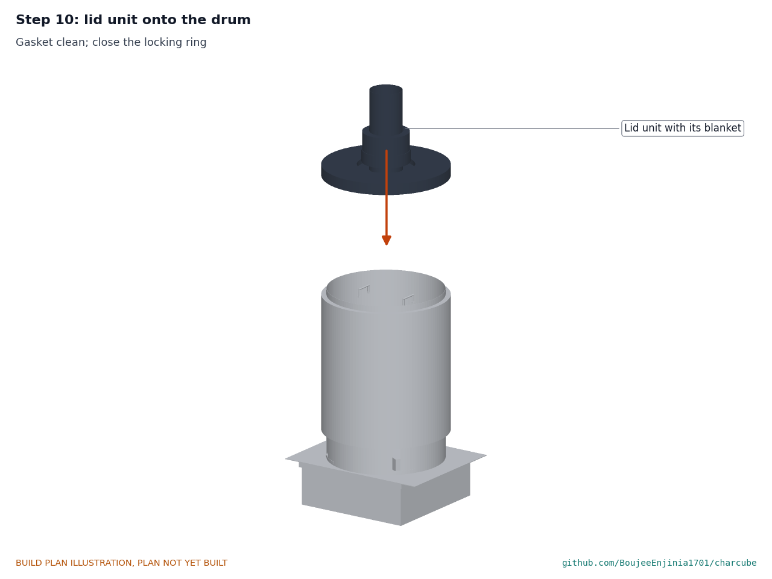
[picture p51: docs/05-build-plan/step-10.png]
Step 10


Gasket clean; lower the lid unit by the throat and close the locking ring.

### Step 11: tap, loose lid and vent onto the jacket

Step 11

Tap into its socket on PTFE tape, lever closed; vent nipple through the lid with a locknut each side; lid loose on the rim.

### Step 12: wrap the jacket blanket

Step 12

From 60 above the bottom to the rim, cut round the tap; tie wire.

### Step 13: legs onto the fins

Step 13

With the jacket upside down on a padded stand, bolt each leg's flat face to its fin, two M10 bolts and nyloc nuts, tight.

### Step 14: foot cleats and pads onto the legs

Step 14

One M10 bolt and nyloc nut through each leg and cleat, snug so the leg can pivot. Turn the unit upright.

### Step 15: heat-recovery unit over the kiln

Step 15

Jacket empty and flue out (safety stop S4). Push the lift bar through the sleeve's top socket and hook the shackle onto its middle. Wind the unit up until its feet are above the top of the throat (about 1.55 m), swing the arm over the kiln, steadying the unit by a leg, and wind it down so the flared sleeve foot finds the throat and slides over it. Pull out the lift bar. **Hold point:** the gap between sleeve and throat is about 2 all round and every foot pad sits flat. To unload later, do the same the other way: wind up, swing the arm a quarter turn and set the unit down to the left of the kiln.

### Step 16: clips and rain cap onto the flue

Step 16

Rivet the three clips 50 up from the foot and the cap legs at the top; rivet the cap onto the legs.

### Step 17: hang the baffle in the flue foot

Step 17

Line the strip's hole up between the two flue holes and push the rod through all three.

### Step 18: flue into the jacket sleeve

Step 18

From a stable step ladder, with a helper, lower the flue until its clips rest on the sleeve rim; the baffle goes down inside the sleeve. Then swing the lifting aid's arm back to its parked place, away from the flue.

### Step 19: logger and probes

Step 19

Seen from the back right. Strap the logger box to the back right leg. Push the core probe through the drum hole into the retort, and the throat probe into the throat. **Hold point:** both probes are pulled out before the retort or the heat-recovery unit is moved.

## 5. First checks

These are the checks a TRL 4 test report would record; this plan only lists them. Requirement numbers are those of CCB-REQ-001.

*Table 2. First checks.*

| Check | Requirement | How | Pass when |
| --- | --- | --- | --- |
| Batch size | R1 | Pack the retort to 600 with bundled residue and weigh what went in | 10 kg or more air-dry |
| Air paths open | R4 | Slide each damper and the band from open to closed; look through the throat's holes; measure the gap under the rain cap | Every damper and the band move by hand; all 30 holes clear; at least 60 from the flue's top edge to the cone all round |
| Gas path sealed | R4 | Retort lid bolted on its gasket; outer lid on its rope gasket and locking ring | No visible gap at either lid |
| Jacket open and tight | R7 | Fill to 540 deep; leave overnight; look at the vent and the centre hole | No drip; vent and hole clear; nothing seals the top |
| Tap | R7 | Open and close the tap with the jacket full | Water runs and stops cleanly |
| Logger | R9 | The two class 1 probes and the block thermocouple in an ice bath and in boiling water against a reference thermometer | Within 5 °C at both points; a day's record on the card |
| Lifts | R11 | Weigh the drained heat-recovery unit on the winch with a hanging scale, and the retort with a batch of char | Unit about 47 kg, lifted only by the winch; retort with char about 16 kg |
| Lifting aid | R11 | Raise the drained unit 100 off the ground and hold it 5 minutes; then raise it 1.55 m and swing it a quarter turn and back | Winch holds; post top moves no more than about 50; the feet clear the throat; footing does not move |
| Outlet height | R12 | Tape from the ground to the flue's top edge | 2.72 m or more |
| Stand | R11 | Push on the jacket top sideways by hand | No movement at any joint; all three pads flat |
| Block temperature | Safety (S3); no requirement | Log the block thermocouple under the fibre board through the first burn | Recorded; no cracking. If a later burn without the board keeps the blocks under about 150 °C, the board may be left off later builds |
| Hot-surface labels | Safety; no requirement | Look at the drum blanket and the jacket blanket from the front | Both labels in place and readable |

## 6. Safety stops

Stop at each point. Carry on only when everything listed is true.

- **S1. Before cutting, drilling or heating either drum.** You know what the drum held, and it was not fuel, solvent, pesticide or anything flammable or toxic; it is empty, washed and open. Paint and liners are burned off outdoors, upwind, with nobody downwind.
- **S2. Before the jacket is used.** It has held water overnight without leaking. The top is open, the vent nipple is clear, and no sealed lid, valve or plug is fitted anywhere.
- **S3. Before the first fire.** The site is bare soil or paving at least 5 m from buildings, fences, dry vegetation and residue piles, not under trees or a roof, with no burning ban and little wind. A fire extinguisher or 50 L of water and a shovel are at hand. A 3 m circle is marked; children and animals stay outside it. Everyone near the kiln wears heat-resistant gloves, eye protection and closed shoes. The jacket is at least three-quarters full. All first checks of section 5 have passed except the ones that need a burn.
- **S4. Before lifting the heat-recovery unit.** The jacket is drained, the flue is cool enough to hold with gloves, both probes are out, and the flue is lifted out. The unit is moved only with the lifting aid's winch, never carried; nobody stands or reaches under it while it hangs, and the winch handle is held until the brake holds. Never move the jacket full (about 85 kg).
- **S5. While the kiln is hot.** Never open the retort or the outer lid: air reaching hot gas or char can flash. Never stand over the flue or downwind of the throat. Stop a batch that smokes heavily. Draw hot water slowly from the tap; never add cold water to a jacket that has boiled dry.
- **S6. Before unloading.** The kiln has stood sealed overnight with every damper and the band closed; the shell is cool to the gloved hand. Tip the char onto bare ground and wet it before bagging.

## 7. Tools, skills and workspace

**Tools.** Angle grinder with thin cutting and flap discs; jigsaw with metal blades; drill with bits from 4.9 to 12 and a step drill to 20; hand rivet tool for 4.8 rivets; hacksaw; bench vice; files; tin snips; scriber, steel rule, tape, square, protractor and a 0.5 m spirit level; a length of 160 pipe and a larger pipe as rolling formers; spanners and a socket set for M6 to M16; a long spanner and a clamped bar for twisting the baffle; countersink; tape measure to 3 m; a 50 kg luggage scale; a reference thermometer. A stable step ladder for the flue and for bolting the lifting aid's arm; a spade and a bucket or mixer for the footing; a hanging scale to 100 kg. The water jacket goes to a welder.

**Skills.** Basic metalwork: marking out, cutting with a grinder and jigsaw, drilling, rolling thin sheet by hand, riveting and bolting. No certified trade is needed except the welder for the jacket. Running the kiln needs someone who has been shown how to light and close down a retort kiln safely.

**Workspace.** An outdoor or well-ventilated workshop for cutting and grinding (sparks travel several metres); an outdoor area for burning paint off the drums; the kiln site of S3 for assembly, since the finished kiln is moved in its three lifts (drum and plinth stay; the lid unit lifts off by hand and the heat-recovery unit by the lifting aid). Leave a clear space about 1.5 m across to the left of the kiln, where the unit is set down.

**Personal protective equipment.** Eye protection and hearing protection for grinding; cut-resistant gloves for sheet and drum edges; a dust mask for cutting blankets; heat-resistant gloves, eye protection and closed shoes for every burn.

## 8. Where the numbers come from

- Model and constructability checks: `cad/src/model.py` (`python cad/src/model.py --check`, 100 checks); STEP and STL exports in `cad/step/` and `cad/stl/`.
- Pictures: `cad/src/build_plan_media.py`, using `.kit/build_views.py`; written to `docs/05-build-plan/` and `cad/drawings/CCB-DWG-101` to `CCB-DWG-116`.
- General arrangement: `cad/drawings/CCB-DWG-001.pdf`, Rev P6.
- Calculations: `docs/04-calcs/01-sizing.md` (CCB-CAL-001 v0.6) and `docs/04-calcs/sizing.py`; masses, tripod and lifting aid section 4, draft and air section 6, jacket section 7.
- Bill of materials: `bom/bom.csv` and `bom/bom-notes.md`.
- Decisions: `docs/decisions/0003-design-for-construction.md` (CCB-DDR-003), with CCB-DDR-001 and CCB-DDR-002; register `docs/06-design-decisions.md` (CCB-DEC-001).
- Requirements: `docs/03-requirements.md` (CCB-REQ-001 v0.9).

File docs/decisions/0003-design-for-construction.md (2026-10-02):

---
doc_id: CCB-DDR-003
title: CharCube design for construction
project: CharCube
doc_type: Design decision record
version: "0.3"
status: Draft
date: '2026-10-02'
author: Amish Chadha
license: CERN-OHL-S-2.0
revisions:
- version: "0.1"
  date: '2026-09-30'
  author: Amish Chadha
  change: Changes that make the concept physically buildable, with the reason for each; made under Amish's 2026-09-30 instruction to make the design physically buildable; open for his review
- version: "0.2"
  date: '2026-10-01'
  author: Amish Chadha
  change: Budget treated as a value-engineering target, with cost question A1 replaced by a value-engineering note
- version: "0.3"
  date: '2026-10-02'
  author: Amish Chadha
  change: 'Accepted by Amish on 2026-10-02, with A2 (fibre board from the first burn, as changed in review) and A3 (flared sleeve); record stays Draft'
---

# 0003: Design for construction

- **Date:** 2026-09-30
- **Status:** accepted. Amish, 2026-10-02: "i approve your recommendations for all 555 open decisions." This covers every change in Tables 1 and 2, with the first burn to confirm that the 150 mm lid hole does not limit draft, and the recommendations in Table 3 (A2 and A3), which are now decided as recommended and recorded in the design decisions register (CCB-DEC-001). The record stays Draft.

## Context

On 2026-09-30 Amish asked for a prototype build plan that shows how each component is made and how it fits the next, and wrote: "If you are realising that the design cannot be built as per concept - fix the design assumptions to match and be physically feasible as you draw the illustrations." The TRL 3 model of CCB-DDR-002 showed what CharCube does, but a constructability review with build123d (overlaps, contacts and clearances between every pair of neighbouring parts) and a part-by-part review of how each is made found twelve places where it could not be built, fixed or used as drawn.

The changes keep what CharCube does: the same two drums, retort fill, gas holes, burner throat, air shroud, secondary air holes, water jacket, baffle, blankets, flue outlet height, tripod footprint and logger. Nothing here changes the pitch or the safety case. Every change is in `cad/src/model.py`, which now builds each component as it is made and runs 68 constructability checks (`python cad/src/model.py --check`): parts that must touch do touch, parts that must not touch are apart by at least the stated clearance, and nothing overlaps. All 68 pass.

## Decision

*Table 1. Changes made to the model, the BOM and the calculations.*

| # | Problem in the concept | Change made | Why this way |
| --- | --- | --- | --- |
| P1 | The four 390 x 190 mm plinth blocks were drawn centred 170 mm each side of the axis, so each pair overlapped by 50 mm (1.8 L of solid block in the same place). | The blocks are laid as a pinwheel: each block's end butts the next block's side, giving a 580 mm square with a 200 mm square hole in the middle. The ash pan lies on top, and the drum's 572 mm rim stands over the blocks all round. | The pinwheel is the only way four blocks of this size make a square big enough for the drum, and the drum's rim is then carried on block everywhere, not on a 3 mm pan spanning a gap. |
| P2 | The lid's hole was 160 mm, the same as the throat pipe's outside diameter, so the throat had nothing to stand on and would drop into the drum; the collar's bore was also 160 mm with nothing joining it to the throat. | The lid hole is 150 mm. The throat stands on the 5 mm ring of lid inside the collar. The collar is rolled from 1.5 mm sheet to fit the throat snugly and is riveted to the lid by six folded tabs; four rivets join the throat to the collar. | The lid, collar, throat and shroud now lift off as one unit, as the precis describes. The 150 mm hole is a little smaller than the throat's 156 mm bore (8 % less area); the draft calculation does not model this entry, so it is listed in the register to confirm. |
| P3 | The air shroud's top ring only touched the throat, with no fixing. Its band damper was drawn 1 mm clear of the shroud with nothing holding it, and at 40 mm tall it could not close the 40 mm intake gap while still on the shroud. | Six tabs folded up from the shroud's top ring are riveted to the throat. The band damper is 60 mm tall, slides on the shroud and is held by an M6 wing screw in a riveted nut; slid down to the lid it closes the intake with 20 mm still on the shroud. | Riveted and folded, no welding, as BOM line 5 requires. The shroud's position and the 40 mm intake are unchanged, so the secondary air sizing stands. |
| P4 | The four sliding port dampers in BOM line 1 were not modelled and had no way to stay on the drum. | Each port has a curved 60 x 122 mm damper of 1.2 mm sheet that slides 55 mm sideways between two 10 mm guide strips, joggled at their ends and riveted to the drum beyond the damper's travel. Everything stays below the blanket's lower edge, 140 mm above the floor. | A sliding damper must be held top and bottom; riveting through the joggled ends keeps the rivets clear of the damper's path. |
| P5 | The three firebricks stood 150 mm from the axis, exactly under the gas holes' 300 mm circle: one brick covered a gas hole completely and two covered parts of others. | The bricks lie with their long side round the retort, centred 200 mm from the axis, so they carry the retort's edge and stay 8 mm clear of every gas hole. | The gas holes must vent freely into the fire under the retort; the edge of the retort base is also its stiffest part. |
| P6 | The retort sits in a 43 mm annulus inside the outer drum, too narrow for hands, and had nothing to lift it by. | Two M8 U-bolt handles through the retort lid, 130 mm each side of centre, nuts and large washers under the lid. They stand 17 mm below the outer lid. | Bought parts, fitted with a drill; the retort with char (15.5 kg) is lifted by its lid, which is bolted on for the whole batch. |
| P7 | The tripod's ring seat was drawn 7 mm below the jacket and outside its footprint (the ring ran from 212 to 232 mm radius, the jacket's edge is at 210 mm), so nothing carried the jacket. The legs were round stand-ins, the foot plates were not joined to them, and a flat ring of 40 x 6 mm bar is hard to roll without a ring roller. | Three 6 mm steel fins are welded to the jacket shell (the jacket is already the one welded part). Each leg is 40 x 40 x 4 mm angle, one face bolted flat to a fin with two M10 bolts. At the ground each leg is pinned by one M10 bolt to a cleat of the same angle, screwed to a 100 x 100 x 6 mm foot pad. The ring seat is gone. | Every joint is face to face and bolted. Two bolts at each fin make the top joints rigid; with pinned feet the tripod is stable. The leg layout keeps the 1.44 m foot circle; legs are 1.55 m long and lean 18 degrees. |
| P8 | The flue had no seat: it could slide down inside the sleeve. Its rain cap posts were drawn inside the flue bore, touching nothing. The pipe was 700 mm long from a foot 50 mm inside the sleeve, which put the outlet at 2.75 m and the cap only 10 mm above it. | The flue is 650 mm long, so its outlet is at 2.70 m as calculated. Three 20 x 20 x 3 mm angle clips riveted 50 mm above its foot rest on the sleeve rim. The rain cap is riveted to three flat-bar legs riveted to the outside of the flue, 60 mm above the outlet. | Restores the outlet height and cap gap used in CCB-CAL-001; the clips carry the flue and the baffle on the jacket. |
| P9 | The baffle's cross bar (10 x 10 x 156 mm) cut into the flue wall and its "notches" held it in no direction. | The baffle strip has an 11 mm hole near its top and hangs on a 10 mm rod, 160 mm long, through two 11 mm holes 15 mm above the flue's foot. The strip is about 615 mm long and stays 3 mm clear of the sleeve and 10 mm above the throat. | The rod is captured by the holes and the baffle by the rod, so both lift out with the flue for cleaning, as decided in CCB-DDR-002 item 12. |
| P10 | The jacket's loose lid floated 2 mm above the rim, and the vent tube stood on nothing. | The lid (1.5 mm, 420 mm, with a 210 mm centre hole) rests on the shell rim, located by three tabs inside it; the 3/4 in vent nipple passes through it, held by two locknuts. | The jacket stays open to the air through the vent and the centre hole; the hole also clears the flue clips. |
| P11 | The logger box was drawn centred on a tripod leg, so the leg passed through it (REVIEW 2026-09-26, appearance item 3). | The box sits beside the leg's flat face, 520 mm up, held by two hose clips. | As recommended in that review item. |
| P12 | The core probe was drawn coming down through the outer lid from inside the air shroud, under its top ring where it could not be inserted, and through the retort lid; a 300 mm probe could not reach the middle of the charge 490 mm below the lid. The throat probe passed through the sleeve's slip joint as well as the throat. | The core probe (now 500 mm) goes in horizontally at the back, through a 10 mm hole in the drum, a slit in the blanket and a 10 x 40 mm slot in the retort, to the axis at mid-fill (300 mm up the charge). The throat probe (300 mm) goes in at the back 70 mm below the jacket, below the sleeve, through an 8 mm hole. | Plain holes, no glands: the annulus and throat are below atmospheric pressure, so little air leaks in, and any retort gas through the slot burns in the annulus as designed. The core probe is withdrawn before the retort is lifted. |

*Table 2. Knock-on changes.*

| Item | Change | Reason |
| --- | --- | --- |
| Masses | Kiln 97 kg (was 96 kg); jacket empty 23.3 kg (fins, thicker loose lid); lift unit 47.4 kg, 23.7 kg each for two people (was 46.6 kg, 23.3 kg); retort with char 15.5 kg; full jacket 85 kg. Tripod leg free length 1.43 m, factor of safety against buckling 58 (was 51) [CCB-CAL-001 section 4]. R11 is still met, with 1.3 kg per person to spare. | Fins, U-bolts, 60 mm band, cleats and pads added; ring seat removed; flue 50 mm shorter. |
| Energy | Flue gas heat at the jacket inlet 61 MJ (was 60 MJ, rounding of a 0.1 MJ change in stored heat); heat to water unchanged at 11.5 MJ; secondary hole area needed 28.6 cm² (was 28.5) against 33.9 cm². No requirement status changed. | Calculations re-run (`docs/04-calcs/sizing.py`). |
| BOM | Lines 1 to 8, 10, 12 to 15 re-specified to the parts above; prices left as they were ($319). | Small parts were added without re-pricing; see Table 3, A1. |
| Drawings and media | CCB-DWG-001 Rev P5; concept sheet CCB-DWG-010 Rev P4; making sketches CCB-DWG-101 to 114; STEP, STL, the interactive model and concept media regenerated. | Follows the model. |

*Table 3. Questions on cost, the safety case and handling; A2 and A3 decided by Amish on 2026-10-02. (A1, on cost, is now a value-engineering note: the added parts are unpriced and probably add $5 to $10 to the $319 estimate against the $320 value-engineering target, and the register's Value engineering section lists the savings worth trying.)*

| # | Question | Options | Recommendation |
| --- | --- | --- | --- |
| A2 | The fire under the retort heats the drum floor, which stands on a 3 mm pan on concrete blocks. Concrete can crack or spall when heated. | (a) build as modelled and measure the block surface temperature on the first burn; (b) lay a 25 mm ceramic fibre board between the pan and the blocks. | (a), with a hold point in the build plan's first checks; (b) if the blocks pass about 150 °C. **Decided by Amish, 2026-10-02, as changed in review:** (b) from the first burn, with a thermocouple on a block; the board is dropped on later builds only if a measured burn without it keeps the blocks under about 150 °C. |
| A3 | The jacket sleeve must be lowered over the throat with 2 mm clear all round, by two people lifting a 47 kg unit to about 1.5 m. | (a) as modelled; (b) flare the bottom 20 mm of the sleeve out to about 190 mm so it guides itself onto the throat (a welding detail for the fabricator). | (b): it costs little at the welder and makes the lift safer. **Decided by Amish, 2026-10-02:** (b). |

## Consequences

- `design_state: constructable` in `project.yaml`. The build plan CCB-BLD-001 shows every component and step in pictures generated from the model (`cad/src/build_plan_media.py`).
- Requirement status is unchanged: six met, five at risk (R2, R3, R5, R6, R8), one not verifiable at TRL 3 (R4) (CCB-CAL-001 v0.4).
- The photoreal renders (`media/render-*.png`), `media/card.png`, `media/social-preview.png` and the appearance model `cad/src/product_model.py` still show the concept's ring seat, round-post rain cap and logger position; they need updating on Amish's Mac, where Blender is. Appearance items 2 and 3 of the 2026-09-26 review (tripod sections, logger position) are now settled by P7 and P11.
- Drum sizes vary by maker; the 43 mm annulus, the retort's bolt ring and the probe slot position must be checked on the drums actually bought.

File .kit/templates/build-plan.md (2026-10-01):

---
doc_id: PRJ-BLD-001
title: Project prototype build plan
project: Project name
doc_type: Build plan
version: "0.1"
status: Draft
date: YYYY-MM-DD
author: Amish Chadha
license: CERN-OHL-S-2.0
revisions:
  - version: "0.1"
    date: YYYY-MM-DD
    author: Amish Chadha
    change: First build plan; design made constructable
---

# Project prototype build plan

**Plan, not yet built.** How to build the first proof-of-concept prototype, component by component. Building and testing to it is TRL 4 work. Decisions still to be made are kept in the design decisions register (`docs/06-design-decisions.md`), not here.

## 1. What you are building

Every component, pulled apart and numbered in build order

One short paragraph: what the prototype is, how many components, which are made and which are bought, and the main ways they are made.

## 2. What changed to make it buildable

| Component | The concept had | The buildable design has | Why |
| --- | --- | --- | --- |

## 3. Making the components

### 3.1 Component name

Making sketch

**What it is and what it is made from.**

**How to make it.**

1. Mark out ...
2. Cut ...

**How it fits the parts next to it.**

Close-up of the joint

**Check before moving on.**

## 4. Putting it together

### Step 1: ...

Step 1

## 5. First checks

| Check | Requirement | How | Pass when |
| --- | --- | --- | --- |

## 6. Safety stops

## 7. Tools, skills and workspace

## 8. Where the numbers come from

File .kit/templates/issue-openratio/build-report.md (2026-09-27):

---
name: Build report
about: Tell us what happened when you built, printed or tested part of this design
title: "Build report: "
labels: build-report
---

This is a research and educational prototype, not a medical device. It is a TRL 3 concept and is not released for fabrication. If you build any part of it, you do so at your own risk. Reports help everyone.

**What you built** (part, sub-assembly or test)

**Materials, tools and settings**

**What worked**

**What did not work, with photos or measurements if you have them**

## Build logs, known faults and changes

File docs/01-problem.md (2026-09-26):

---
doc_id: CCB-PRB-001
title: CharCube problem statement
project: CharCube
doc_type: Problem statement
version: "0.4"
status: Draft
date: '2026-09-26'
author: Amish Chadha
license: CERN-OHL-S-2.0
revisions:
- version: "0.1"
  date: '2026-09-24'
  author: Amish Chadha
  change: Initial scaffold
- version: "0.2"
  date: '2026-09-25'
  author: Amish Chadha
  change: Populate to TRL 2 (problem, users, context, constraints, out of scope, prior work with sources)
- version: "0.3"
  date: '2026-09-25'
  author: Amish Chadha
  change: Record Amish's 2026-09-25 decisions (CCB-DDR-001) on feedstock, budget and co-design partners; scale figures from CCB-CAL-001
- version: "0.4"
  date: '2026-09-26'
  author: Amish Chadha
  change: Stronger sources; kiln budget $320 (budget top-up approved by Amish)
---

# CharCube problem statement

Crop residue gets burned in the open, releasing carbon and smoke. Farmers burn it because it is the fastest and cheapest way to clear a field between harvests, and nothing nearby pays for it. CharCube is a small batch retort kiln, built from two steel drums, that turns a farm's residue into biochar for its own soil, burns the smoky gas instead of venting it, and returns some of that heat as hot water. Design with, not for: requirements must come from co-design sessions and field trials with the intended users through a local partner.

## The problem

Open burning of crop residue is large, seasonal and harmful:

- **Scale.** India alone generates about 500 Mt of crop residue a year and burns about 100 Mt of it in the field ([Lan et al. 2022, *Nature Communications*](https://www.nature.com/articles/s41467-022-34093-z)). World rice straw production is about 370 to 520 Mt a year, and much of it is burned where the next crop follows quickly ([Van Hung et al. 2020](https://link.springer.com/chapter/10.1007/978-3-030-32373-8_1)).
- **Health.** In India, residue burning was linked to an estimated 44,000 to 98,000 premature deaths a year from particulate exposure between 2003 and 2019, with downwind PM2.5 peaks of 200 to 1,200 µg/m³ during the burning season ([Lan et al. 2022](https://www.nature.com/articles/s41467-022-34093-z)).
- **Carbon.** Burning returns almost all of the residue's carbon to the air as CO₂, plus methane, carbon monoxide and black carbon. Turning the same residue into biochar can keep a large share of its carbon in the soil for a century or more: the IPCC default is that 65 to 89 % of biochar carbon remains after 100 years, depending on production temperature ([IPCC 2019 Refinement, Vol. 4, Ch. 2, Appendix 4](https://www.ipcc-nggip.iges.or.jp/public/2019rf/pdf/4_Volume4/19R_V4_Ch02_Ap4_Biochar.pdf)).

Making biochar badly can undo much of the benefit. Traditional earth and pit kilns emit large amounts of methane and carbon monoxide. Field measurements of medium-sized kilns in rural tropical areas found about 54 g of methane per kilogram of charcoal from traditional kilns and about 24 g/kg from improved retort kilns ([Sparrevik et al. 2015, *Biomass and Bioenergy*](https://www.sciencedirect.com/science/article/abs/pii/S0961953414005170)). At a 100-year global warming potential of about 28, 24 g of methane is about 0.7 kg CO₂e per kilogram of char, a large fraction of the carbon the char stores. The gas has to be burned, not vented.

Three gaps remain for smallholders:

- **Cost and skill.** Proven designs such as the Adam retort are brick or steel structures sized for charcoal businesses; flame-curtain (Kon-Tiki) kilns are cheap but open-topped and waste their heat.
- **Wasted heat.** Every design burns its pyrolysis gas to protect the air, but few put the heat to use. A household that also heats water on a wood or dung fire gains a second reason to run the kiln.
- **Evidence.** Few low-cost kilns publish temperature logs, so a user cannot tell whether a batch reached the 450 to 600 °C needed for stable char.

## Users and context

| User | Need | Context |
| --- | --- | --- |
| Smallholder farmer with cereal or cotton residue | Clear residue without open burning; make a soil amendment from it | Rice, wheat, maize or cotton; short gap between harvest and sowing; residue often wet or bulky |
| Farm household | Hot water for washing and cleaning from the same fire | Water often heated on wood, dung or LPG |
| Farmer group, cooperative or NGO | Several kilns shared between farms, with records of how much char each batch made | Village or block level; carbon or soil-health programs |
| Agricultural extension worker or researcher | A cheap, repeatable kiln with logged temperatures, to compare feedstocks and char quality | Research station, college farm, field trials |
| Local fabricator | A design built from standard drums and pipe with hand tools, drill and angle grinder | Village workshop; welding available for one part only |
| Open hardware community | A documented, open reference retort with honest numbers | Makerspaces, university labs, NGOs |

## Constraints

- Garage-buildable prototype, concept budget $320 USD for kiln parts (raised from $300 by the budget top-up approved by Amish, 2026-09-26, CCB-DDR-002 item 17). The safety kit (about $40) is required and listed separately, outside that budget (decided by Amish, 2026-09-25, CCB-DDR-001 item 2).
- Built from standard 200 L (55 US gal) and 114 L (30 US gal) open-head steel drums, plain (not galvanized) steel pipe and bought fittings.
- Outdoor, batch operation by one or two adults, one batch a day, with cooling overnight.
- No electricity needed to run the kiln. The temperature logger may use a small USB power bank.
- Must burn its pyrolysis gas under all normal operating conditions; smoke only during light-up.
- Hot water circuit open to the air (unpressurized) so it cannot build pressure.
- Feedstock is low-density crop residue: loose rice straw is only 13 to 18 kg/m³ dry ([Van Hung et al. 2020](https://link.springer.com/chapter/10.1007/978-3-030-32373-8_1)) and chopped wheat straw about 36 to 43 kg/m³ ([Chevanan et al. 2010, *Bioresource Technology*](https://www.academia.edu/6707237/Bulk_density_and_compaction_behavior_of_knife_mill_chopped_switchgrass_wheat_straw_and_corn_stover)), so it must be packed, bundled or mixed with denser stalks and cobs to fill a drum usefully. Decided by Amish, 2026-09-25 (CCB-DDR-001 item 4): the design targets bundled straw and mixed stalks and cobs first; loose straw needs a press, which is a separate project.

## Out of scope

- Clearing a whole field in one season. At 12.0 kg per batch (CCB-CAL-001), one kiln handles about 3.0 t of air-dry residue a year; a hectare of rice leaves several tonnes of straw. CharCube serves a household's or a trial plot's residue, and a cooperative would need several kilns. This scale gap is stated plainly in CCB-REQ-001.
- Selling charcoal for cooking fuel.
- Certified carbon credits. Certification (for example the [European Biochar Certificate](https://www.european-biochar.org/en)) needs lab analysis and audited records beyond this project; the logger only supports it.
- Pressurized hot water, space heating or connection to household plumbing.
- Wet feedstock (manure, food waste) that needs drying first.

## Prior work

- **Adam retort (Improved Charcoal Production System).** A brick retort that burns its volatiles in a separate chamber and uses the heat to speed carbonization; reported conversion efficiency of 30 to 42 % against 10 to 22 % for earth mounds, up to 75 % lower emissions and a 12 h cycle ([Adam 2009, *Renewable Energy*](https://doi.org/10.1016/j.renene.2008.12.009)).
- **Field emissions of retort kilns.** Retorts cut methane by about 56 % and carbon monoxide by about 67 % against traditional kilns, but yield was not significantly higher, partly because start-up needs extra wood ([Sparrevik et al. 2015](https://www.sciencedirect.com/science/article/abs/pii/S0961953414005170)). CharCube's start-up fuel is therefore counted in its energy budget.
- **Kon-Tiki flame-curtain kilns.** Open cone kilns that need no start-up fuel; measured char yield of 22 ± 5 % on a dry mass basis, 76 ± 9 % carbon, methane 30 ± 60 g/kg and CO 54 ± 35 g/kg of biochar ([Cornelissen et al. 2016, *PLOS ONE*](https://journals.plos.org/plosone/article?id=10.1371%2Fjournal.pone.0154617); [Schmidt and Taylor 2014, *the Biochar Journal*](https://www.biochar-journal.org/itjo/media/doc/1437139451142.pdf)). They are the main low-cost alternative to CharCube.
- **Nested-drum retorts.** Two-drum retorts with the gas vented from the inner drum into a fire in the annulus are widely built by hobbyists and extension projects. Specific published designs were not verified for this note and are not cited.
- **Biochar persistence.** The IPCC gives default fractions of biochar carbon remaining after 100 years (0.65 low, 0.80 medium, 0.89 high temperature) and default organic carbon contents (0.49 for rice husk and straw char, 0.65 for herbaceous material) ([IPCC 2019](https://www.ipcc-nggip.iges.or.jp/public/2019rf/pdf/4_Volume4/19R_V4_Ch02_Ap4_Biochar.pdf)). Later work argues most carbon in well-made biochar persists far longer ([the Biochar Journal](https://www.biochar-journal.org/en/ct/109)). CharCube uses the IPCC defaults, which are conservative.

## Open questions

- Which region and residue first: paddy straw in northwest India, maize and cotton stalks in East Africa, or another? Proposed, awaiting Amish. The partner is chosen per area later (portfolio decision by Amish, 2026-09-25).
- Is hot water valued enough to justify the water jacket, or would users rather have a lower-cost kiln without it?
- How will users bundle straw by hand, and how much stalk or cob must be mixed in to reach about 120 kg/m³? A press is a separate project.
- Where will the char go: own fields, a cooperative's compost, or a buyer?
- Do local open-burning rules restrict running a kiln during burning bans?

## User research and co-design

This design is for communities the author is not part of, so requirements come from the people who will use it.

- [ ] Identify a local partner organization (Helpful Engineering network, NGO or university); chosen per area later, by Amish
- [ ] Run co-design sessions with intended users; record who, where and what was learned
- [ ] Validate load, distance, terrain and cost assumptions in the field
- [ ] Revise requirements (REQ) from findings before freezing the design

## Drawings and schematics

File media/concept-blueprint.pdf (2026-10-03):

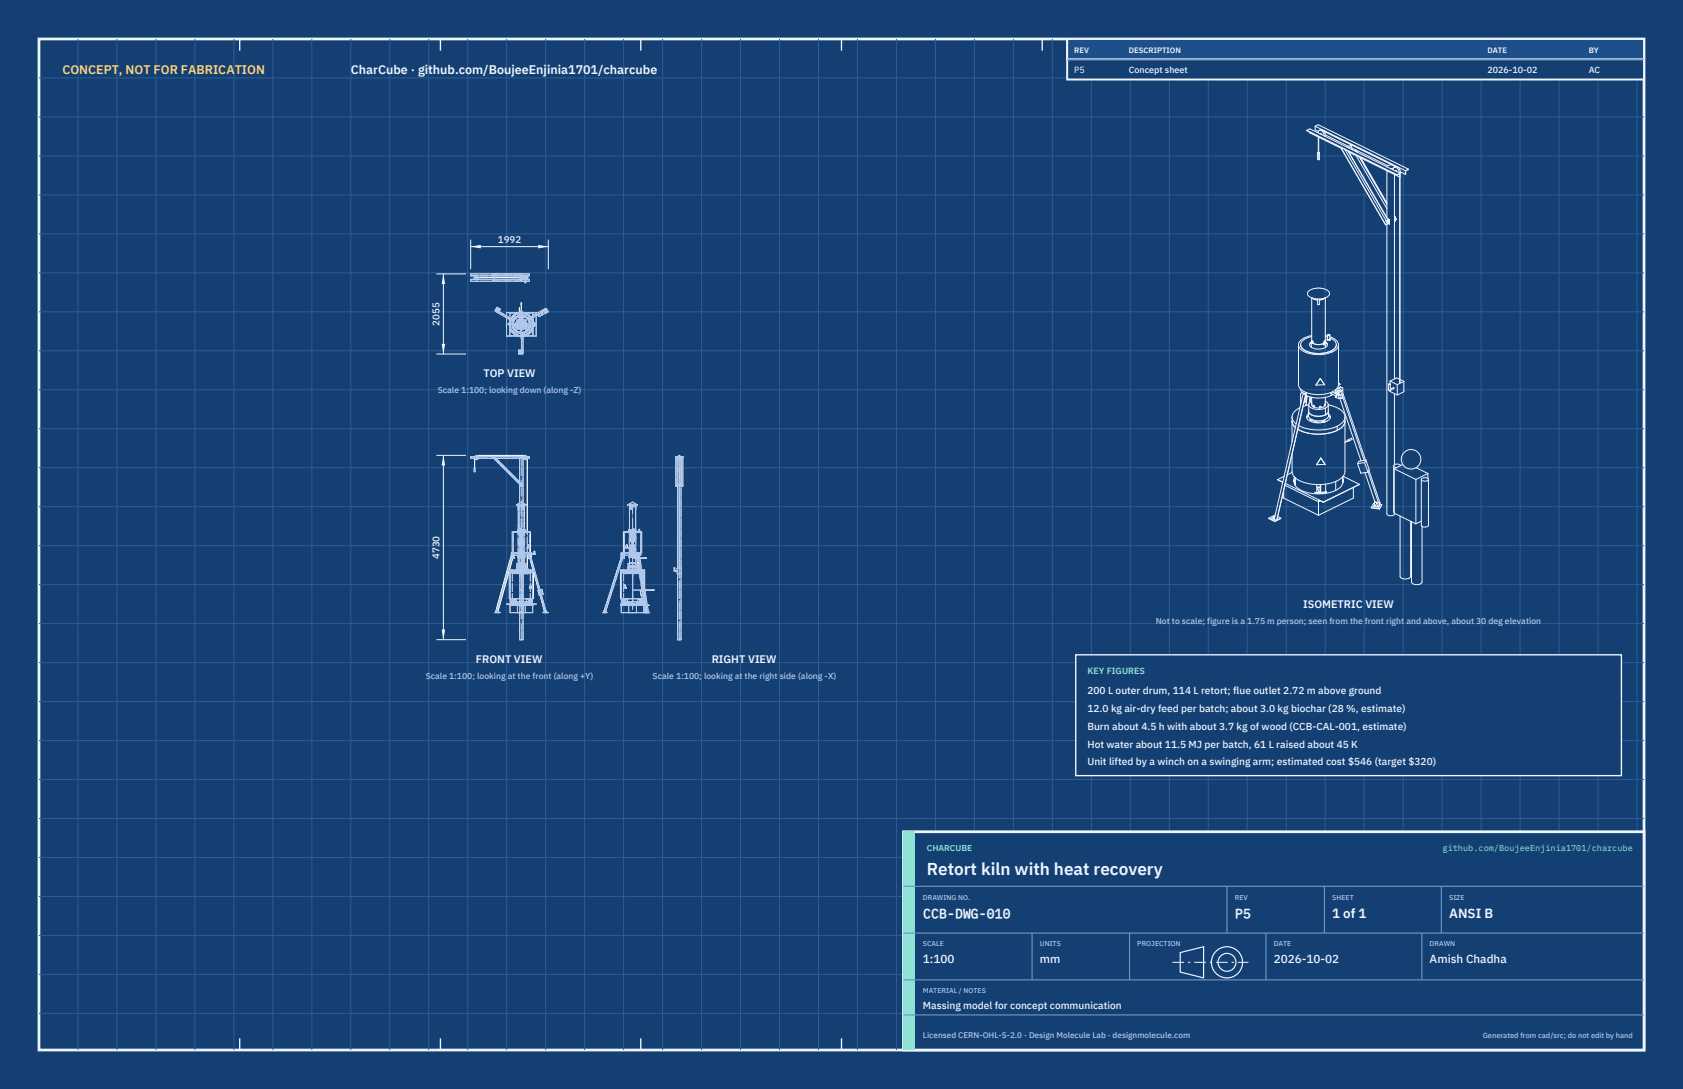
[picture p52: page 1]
CONCEPT, NOT FOR FABRICATION; CharCube · github.com/BoujeeEnjinia1701/charcube; FRONT VIEW; TOP VIEW; RIGHT VIEW; ISOMETRIC VIEW; REV; DESCRIPTION; DATE; Concept sheet; CHARCUBE; github.com/BoujeeEnjinia1701/charcube; DRAWING NO. CCB-DWG-010; REV P5; SHEET 1 of 1; SIZE ANSI B; SCALE 1:100; UNITS mm; PROJECTION; DRAWN Amish Chadha; Licensed CERN-OHL-S-2.0 · Design Molecule Lab · designmolecule.com; Generated from cad/src; do not edit by hand

Scale 1:100; looking down (along -Z)

Not to scale; figure is a 1.75 m person; seen from the front right and above, about 30 deg elevation

KEY FIGURES
200 L outer drum, 114 L retort; flue outlet 2.72 m above ground
12.0 kg air-dry feed per batch; about 3.0 kg biochar (28 %, estimate)
Burn about 4.5 h with about 3.7 kg of wood (CCB-CAL-001, estimate)
Hot water about 11.5 MJ per batch, 61 L raised about 45 K
Unit lifted by a winch on a swinging arm; estimated cost $546 (target $320)

Scale 1:100; looking at the front (along +Y)

Scale 1:100; looking at the right side (along -X)

Retort kiln with heat recovery

MATERIAL / NOTES
Massing model for concept communication

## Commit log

2026-09-24 Initial scaffold: standard open hardware layout, CERN-OHL-S v2 + MIT licenses
    Claude-Session: https://claude.ai/code/session_01XuhhSU4W6fYhgCfURbrkut
    [bom.csv]
2026-09-25 Adopt portfolio kit v1.3.0: session commands, scale figure, 3D viewer, flow diagrams
    Adds .claude/commands (/populate, /advance-trl3, /rein-in, /refresh-media)
    so every Claude Code session starts from the standard prompts, and extends
    concept media with a 1.75 m scale figure, an interactive glTF viewer and
    system or energy flow diagrams. TRL cap 3 unchanged.
    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
2026-09-25 Kit v1.3.1: renderer fixes from the TremorTrace pilot
    Context scale parts for small objects, cutaway exclusions, and text
    labels in flow diagrams.
    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
2026-09-25 Populate charcube to a strong TRL 2 with concept media (overnight batches 4 and 5)
    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
    [bom.csv]
2026-09-25 Advance charcube to TRL 3 (batch 4)
    Decisions approved by Amish 2026-09-25 recorded in DDR-001. TRL 4 is on hold.
    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
    [bom.csv, charcube-assembly.step, charcube-assembly.stl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]
2026-09-26 Accept all recommendations (DDR-002), switch footer to designmolecule.com, add README write-up with new inspiration point
    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
    [bom.csv, charcube-assembly.step, charcube-assembly.stl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]
2026-09-26 Strengthen sources, apply approved budgets, add CITATION.cff and CONTRIBUTORS.md with credits
    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
    [results.csv]
2026-09-27 Product appearance model and photoreal renders
    Adds cad/src/product_model.py (appearance model for renders only, all main
    dimensions from model.py) and Blender renders in media/render-*.png,
    captioned with the project, repository and viewing direction. README leads
    with the product render; trl stays 3.
    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
2026-10-01 Image quality pass: legible exploded views, flow diagrams and drawing sheets
    Kit 1.6.1 image layout: the parts list sits in its own column, number bubbles sit on visible parts and never overlap, small parts get a leader, pictures are cropped to the subject, flow labels keep numbers with their units, and sheet captions and the revision table no longer overprint. Concept images, blueprint and general arrangement sheet regenerated; repo-specific labels moved clear of other text and lines.
2026-10-01 Kit 1.7.0: constructable design, illustrated build plan and design decisions register
    The design is now constructable: every part can be made and fits its neighbours, with each change recorded in a Design for construction decision record (made under Amish's 2026-09-30 instruction; ope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
    [bom.csv, charcube-assembly.step, charcube-assembly.stl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]
2026-10-01 Budget treated as a value-engineering target
    Amish, 2026-10-01: the budget is a hypothetical control target that keeps the design on a value-engineering lens, not a spending limit. Documents now state the value-engineering target and the estima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
2026-10-02 Record Amish's approval of the open-decision recommendations
    Amish approved the recommendation on every open decision in the design decisions register ("i approve your recommendations for all 555 open decisions.", 2026-10-02). Each decision is moved to Decisio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
    [bom.csv]
2026-10-03 Carry approved follow-ups into the design and redo photoreal renders
    Amish approved the follow-up actions from the open-decision sign-off ("APPROVED CHANGES, COMPLETE THESE", 2026-10-02), the design-for-construction change tables in ten repos, the last wave's open dec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
    [bom.csv, charcube-assembly.step, charcube-assembly.stl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]
2026-10-03 Record Amish's 2026-10-03 decisions; FlatTrike fork and PotPress guard fixes
    Amish, 2026-10-03: "PalletPilot - i accept it"; "FlatTrike - i accept your design recommendation, proceed and execute the solution for fork direction or caster"; "PotPress - move forward with the four guard fixes. I accept the cost."; "GravitySort - i accept your recommendation"; "TIght Margins - i accept the margins"; "Cost over target - i accept all the cost variations and overruns". FlatTrike knuckle forks turned to trail (35 mm trail); PotPress finer mesh, small-hole plates, top beam and crank bracket covers, ISO 13857 desk check now met on paper. Registers, requirements, drawings, pictures, renders and PDFs upd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

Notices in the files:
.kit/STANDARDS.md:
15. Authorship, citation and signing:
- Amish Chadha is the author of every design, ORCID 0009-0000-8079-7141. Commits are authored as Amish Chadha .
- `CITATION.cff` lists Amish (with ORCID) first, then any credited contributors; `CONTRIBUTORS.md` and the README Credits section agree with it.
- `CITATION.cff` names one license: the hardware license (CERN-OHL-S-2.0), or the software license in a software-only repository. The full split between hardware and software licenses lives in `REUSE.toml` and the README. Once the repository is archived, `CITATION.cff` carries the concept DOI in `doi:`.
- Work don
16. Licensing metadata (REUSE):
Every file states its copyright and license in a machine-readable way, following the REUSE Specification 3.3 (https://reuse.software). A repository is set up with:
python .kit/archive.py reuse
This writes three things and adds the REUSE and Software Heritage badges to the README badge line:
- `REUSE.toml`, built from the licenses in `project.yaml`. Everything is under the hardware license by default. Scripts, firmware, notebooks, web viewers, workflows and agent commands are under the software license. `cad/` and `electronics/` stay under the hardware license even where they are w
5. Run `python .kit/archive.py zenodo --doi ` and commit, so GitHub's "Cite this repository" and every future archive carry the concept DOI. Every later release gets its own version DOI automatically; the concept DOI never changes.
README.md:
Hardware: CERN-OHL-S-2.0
